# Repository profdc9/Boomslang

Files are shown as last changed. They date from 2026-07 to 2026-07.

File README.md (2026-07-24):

# Boomslang




A 3-channel ESP32-S3 pyrotechnic/model-rocket ignition controller. Hardware
(KiCad project, schematic, gerbers) is under `Boomslang/`; firmware is under
`firmware/` (PlatformIO, Arduino framework).

## ⚠️ Disclaimer — use at your own risk

This project fires pyrotechnic devices and/or model rocket motors. Incorrect
wiring, misconfiguration, a firmware bug, a hardware fault, or plain
operator error can cause unintended ignition, fire, injury, or property
damage. **This is a hobbyist project, provided AS-IS, with NO WARRANTY OF
ANY KIND** — express or implied, including no warranty of merchantability,
fitness for a particular purpose, or that it is safe, correct, reliable, or
free of defects.

By building, modifying, or using this hardware or firmware, you accept full
responsibility for:

- Verifying correct operation yourself, on your own hardware, before relying
  on any of it — including every safety feature described in this README.
- Complying with all applicable laws, regulations, and permitting
  requirements for pyrotechnics, explosives, and/or model rocketry in your
  jurisdiction.
- Following standard range-safety practice: safe distances, no bystanders
  in range, appropriate PPE, a real mechanical arm switch you trust, and
  never treating any software feature here as a substitute for that.

The author(s) and contributors accept **no liability** for any injury,
death, damage, or loss arising from building, modifying, or using this
project, to the fullest extent permitted by law.

## License

Dual-licensed by design, since this repo mixes source code and hardware
design files:

- **Firmware** (`firmware/`) is licensed under the [MIT License](LICENSE).
- **Hardware design files** (`Boomslang/` — KiCad schematic, PCB, gerbers)
  are licensed under [CC BY-SA 4.0](LICENSE-HARDWARE.txt).

Both are permissive and allow commercial use, but neither one waives the
disclaimer above — "you can use/modify/redistribute this" is a separate
question from "this is safe or fit for any particular purpose."

## WiFi access

The board hosts its own WiFi AP (no router needed) — SSID and password are
persisted settings (`wifiSsid`/`wifiPassword`, settings page), defaulting to
`boomslang` / `liftoff!`. **The password is this device's only access
control** — there's no separate login on top of it, so anyone who has it can
arm and fire. Change it from the default before using this anywhere it
matters. A password can also be left blank for an open, unencrypted network,
but that isn't recommended for the same reason.

Changes take effect only after the device is power-cycled or reset (the AP
isn't re-initialized at runtime) — you'll need to reconnect using the new
name/password afterward. SSID must be 1-32 characters; password must be
empty or 8-63 characters (the minimum WPA2-PSK allows).

The control pages are served over plain HTTP, not HTTPS — WPA2 already
encrypts the WiFi link itself, and adding TLS on top would mean a
self-signed certificate that a phone would flag as untrusted on every visit,
plus added latency on the page's frequent status polling, for a narrower
additional threat (another authenticated client on the same AP sniffing
traffic) than what WPA2 already covers.

**Relay (station) mode** (`wifiStationMode`, default **off**): instead of
hosting its own AP, the device can join `wifiSsid`/`wifiPassword` as a
client of an existing router, to relay through it when the operator needs
more distance from the pyrotechnics than the device's own AP range allows.
If it can't connect within 15 seconds (wrong password, out of range, router
down), it falls back to hosting its own AP instead — so a bad relay network
never leaves you locked out of the device with no way to disarm or abort.

This setting is deliberately **not a checkbox** on the settings page:
enabling it means anyone who can reach that external network can also reach
this device, so it requires typing the literal word `relay` into a text
box rather than a single accidental tap — blank or anything else both mean
"stay off, host my own AP" (the safe default), including if the field is
missing from the request entirely.

**Before you enable this, secure that router/network yourself — it's now
part of your access control, not just Boomslang's own password.** In its
own AP mode, WPA2 on the device is the entire perimeter. In relay mode,
that perimeter is whatever the router enforces: WPA2/WPA3 with a strong
password of its own, no other untrusted devices or guests on it, and
ideally a network used for nothing but this. A relay network that's open,
weakly secured, or shared with devices you don't control gives *anyone on
it* the same access as someone standing next to the device with its own
password — arming and firing included.

Either way — hosting an AP or joined as a station — the device also starts
an mDNS responder, so `http://boomslang.local` works regardless of which
mode ended up active or what IP a router's DHCP server happened to assign.

## Web UI pages

Four pages, all polling `/status.json` and posting to the same handful of
endpoints — the split below is purely how the browser organizes things, not
a backend/data-model split. Each has a small nav row (Main · Timing · Stats
· Settings) so it's obvious how to get back to the others.

- **`/` (Main)** — the operational screen, meant for actual field use:
  arm/fault/lockout status, battery voltage, each channel's checkbox + live
  continuity/firing state, and TRIGGER/ABORT/PANIC. Deliberately lean —
  timing setup and post-fire review live elsewhere so this screen stays fast
  to read and tap through during an actual arm/fire sequence.
- **`/timing`** — setup screen: the same channel checkboxes as Main (same
  `/select` endpoint — selection can be changed from either page) plus each
  channel's offset/duration in milliseconds and optional PWM cycling
  (Hz/duty%, see Trigger sequence below). No live operational state and no
  TRIGGER/ABORT/PANIC here.
- **`/stats`** — read-only review: peak and average current per channel
  from its most recent pulse (see Trigger sequence below).
- **`/config` (Settings)** — every persisted setting described throughout
  this README.

## Overcurrent fault protection

Each channel's IRLZ44N MOSFET has its own analog overcurrent comparator
(transistors Q5/Q10/Q16, sensing the 0.05Ω source shunt) that pulls that
channel's own gate to GND in hardware, in nanoseconds, with **no firmware
involved at all**. That's the actual protection for the transistor. All
three channels' comparators also pull a single shared, open-collector,
active-LOW `FAULT` line (GPIO1) — since it's wired-OR across all three,
firmware can tell *that* a channel faulted, but not *which* one.

The 0.05Ω figure above is just the schematic default (R1/R17/R31) — the
per-channel shunt resistance (`senseOhms`, settings page) is a runtime
setting used for the firing-current math (`readCurrentA()`), independently
of the comparator's own fixed hardware trip point. Valid range is
**0.01Ω–100Ω**, to accommodate a field-replaced shunt of a different value.

**The fault ISR** (`onFaultISR` in `firmware/src/main.cpp`) is a level-1
`attachInterrupt` on `FAULT`, `IRAM_ATTR`, and deliberately minimal: it does
exactly two things, a single register write forcing all three TRIGGER
outputs HIGH at once (not just the channel that faulted — the shared line
can't tell which one anyway, so every channel is shut down for consistency)
and setting a sticky `faultLatched` flag. Nothing else runs in the ISR
itself — no `Serial`, no heap, and critically no `analogRead()`, since the
ESP-IDF ADC driver takes a FreeRTOS mutex internally that `loop()` is
already holding on a regular basis; taking it again from ISR context would
be undefined behavior.

**Sampling SENSE for diagnostics** (which channel was drawing how much
current right as the fault hit) therefore happens in a separate,
dedicated FreeRTOS task (`faultSampleTask`), woken by the ISR via
`vTaskNotifyGiveFromISR`/`portYIELD_FROM_ISR` so it runs essentially the
instant the ISR returns, ahead of `loop()` or anything else. It's pinned to
the core opposite the Arduino loop/web server, at a priority high enough to
preempt normal code but below WiFi's own internal tasks. This snapshot is
best-effort — the hardware protection may have already cut current before
it runs — and is exposed as `fault_snapshot_a` in `/status.json` and shown
in the FAULT banner on the control page. If the banner reads "FAULT —
overcurrent detected" with no `(X.XXA Y.YYA Z.ZZA)` after it, that means
`fault_snapshot_a` was never populated for this event — either
`writeTriggerPinBlanked()`'s own fallback latched the fault directly
(covered below; it takes its own snapshot too, since it's normal task
context rather than ISR context and can safely call `analogRead()`
itself, unlike `onFaultISR()`), or a fault was latched some other way that
doesn't notify `faultSampleTask` (the boot-time check, for example).

**Clearing a fault**: `faultLatched` is a software latch, not
self-clearing. It clears automatically — no button, no endpoint — the
instant the device is `DISARMED` and the hardware `FAULT` line re-checks
clear (several reads over ~2ms, so a line chattering right at the trip
point doesn't get cleared into a still-live fault; see `loop()`'s
DISARMED-only fault-clearing pass in `main.cpp`). It's tied specifically
to being disarmed — never while armed, so a fault mid-sequence can't clear
itself out from under an operator who hasn't actually disarmed — which
matches the fact that a disarm+rearm is already required before
retriggering anyway (see `faultLockedOut()` below); there was no reason to
also require a separate manual "clear fault" button on top of that. A
reboot doesn't clear a persistent fault either: `FAULT` is checked at
boot, before the ISR is even attached, and latches immediately if still
asserted.

**Fault lockout** (`faultLockedOut()`/`notifyFaultOccurred()`,
`arm_state.cpp`): independent of `faultLatched` above — that flag only
tracks whether a fault is *currently* asserted/unacknowledged, and clears
automatically as soon as it's genuinely resolved and the device is
disarmed. This is a separate, sticky flag: once any fault has occurred, it
stays set — same shape as the PANIC lockout — unconditionally requiring a
fresh disarm+rearm before another TRIGGER is accepted, regardless of
`requireRearmAfterFire`, even after the fault itself has already cleared.
Cleared at the same disarm→rearm transition point every other lockout is.

**Live FAULT line indicator**: the main control page also shows a
`FAULT line: clear/ASSERTED` readout (`fault_pin_active` in
`/status.json`, a plain `digitalRead(PIN_FAULT)` taken fresh on every
poll), separate from the latched `fault` flag above. Since `faultLatched`
only clears automatically while disarmed, this raw reading is what tells
you whether the hardware comparators are asserting the line *right now* —
useful for telling "latched from a past event, line's gone high again"
apart from "still actively faulted."

**Leading-edge blanking on trigger-pin switching**: on real hardware,
pressing TRIGGER with no igniter/load connected was found to produce an
immediate `FAULT` with a 0A current snapshot — a switching transient at the
moment a trigger pin changes state, not a real overcurrent event (confirmed
by walking the actual shunt/comparator/snubber netlist: the RC snubber ties
drain-to-GND directly, not through the sense shunt, so there's no real
current path for a genuine fault with nothing connected). `firmware/src/
main.cpp`'s `writeTriggerPinBlanked()` now wraps the two deliberate
trigger-pin writes (fire-start in `startFirePulse()`, and the normal
pulse-end release in `loop()`) in a short critical section
(`FAULT_BLANKING_US`, `config.h`, default 10µs — tuned down from an
initial 30µs guess after bench testing confirmed the real switching
transient clears well within that window): interrupts are disabled
for that window, the pin is written, and `FAULT` is checked once directly
afterward — if it's already resolved, that reading is trusted and the
event is treated as filtered, not a fault.

Two subtleties this required getting right, since a plain
`delayMicroseconds()`-based wait would not have been safe here:

- `noInterrupts()`/`interrupts()` (not `detachInterrupt()`/
  `attachInterrupt()` + a bare delay) bounds the window deterministically —
  a plain busy-wait doesn't block task preemption, so a higher-priority
  task/ISR becoming ready mid-wait could otherwise extend the real gap well
  past `FAULT_BLANKING_US`. `delayMicroseconds()` itself is safe to call
  with interrupts disabled: it polls `micros()`, which reads a free-running
  hardware counter that keeps advancing regardless of the core's
  interrupt-enable state — unlike `delay()`/`vTaskDelay()`, which actually
  depend on the tick interrupt to wake back up, and would hang here.
- Disabling interrupts at the CPU level only defers *servicing* — it
  doesn't stop the GPIO peripheral's own edge-detector from latching a
  FALLING edge into its interrupt-status register during the window. Left
  alone, a transient that resolves *inside* the window would still fire
  `onFaultISR()` retroactively the instant interrupts are re-enabled, for
  an edge that's already history. `writeTriggerPinBlanked()` explicitly
  clears that latched status bit (`GPIO_STATUS_W1TC_REG`) before
  re-enabling, so a resolved transient is actually discarded.

None of this touches the real transistor protection described above — the
per-channel analog comparators keep working purely in hardware throughout,
completely independent of whether this interrupt is masked. What's
filtered is only the shared-line firmware echo (forced shutoff + the
sticky latch) reacting to a switching artifact instead of a real fault.

**Why `FAULT_BLANKING_US` isn't 0**: it's tempting to think a shorter
window is strictly better (less time other channels go unprotected by the
shared-line echo — the per-channel hardware protection is never affected
either way). Bench testing found a real lower bound, though: at `0`
(no wait at all), a genuine fault could be missed by `writeTriggerPinBlanked()`
entirely rather than filtered — the comparator's own output hadn't
necessarily finished settling into a stable level by the instant this
function checks it, so a real, ongoing fault could read as
"already resolved" and get discarded, only to be caught later by some
other, slower path with no diagnostic snapshot at all. `10µs` reliably
avoids that while still filtering the original no-load transient. The
delay also determines *where* on the fault current's natural rise/decay
curve the diagnostic snapshot below lands: shorter delay samples closer to
the true peak, longer delay samples further into the decay (current
doesn't collapse to zero the instant the comparator trips — the driver
stage and any loop inductance both take some real, if small, additional
time). `10µs` was chosen empirically on the bench, not derived
analytically — if the real transient/settling duration ever needs to be
known precisely, `DEBUG_FAULT_TIMING`/GPIO13 above is there for exactly
that.

**`writeTriggerPinBlanked()`'s fallback and multi-channel shutoff**: if
`FAULT` is still asserted once the blanking window elapses, this function
also samples SENSE for its own diagnostic snapshot (same reasoning as
`faultSampleTask` above — normal task context, so `analogRead()` is safe
here too) and forces every trigger pin off via the same atomic register
write `onFaultISR()` uses, mirroring what the ISR does for a fault that
isn't coincident with a trigger-pin write. This closes a real gap found
during testing: with a real load on one channel and a short on another,
if the short's fault was caught by this fallback (i.e. it happened right
at that *other* channel's own trigger-pin write) rather than by
`onFaultISR()`, the loaded channel could keep firing for longer than
intended — this function used to only set the sticky fault flags and rely
on `loop()`'s later `stopSequence()` call to shut off *other* channels,
reached only after that iteration's other work (continuity checks, etc.).
Forcing every pin off directly here, immediately, closes that gap the
same way the ISR always has.

The sampling happens *before* that forced shutoff, deliberately: forcing
every channel off first, before sampling, was found to reliably collapse
the diagnostic reading to 0A — unlike the local hardware protection, which
reacts in true analog time and was never the bottleneck here,
`analogRead()` itself is not deterministic (the underlying ESP-IDF driver
power-cycles the whole ADC peripheral and takes an internal mutex on every
single call), so forcing a shutoff immediately beforehand left nothing
meaningful to measure by the time sampling actually ran. Sampling first
trades a small amount of additional, ADC-read-bound latency before *other*
channels are forced off, for a snapshot that's actually usable — still
bounded well under the IRLZ44N's ~1ms SOA tolerance, just no longer
effectively instantaneous the way the plain register write is on its own.

Why a plain level-1 interrupt is enough: the IRLZ44N's SOA tolerates ~1ms at
full overcurrent, and even level-1 ISR latency on this chip is reliably
single-digit microseconds — comfortably inside that margin, especially
given the hardware analog protection has already started cutting current
before the ISR even runs. A `DEBUG_FAULT_TIMING` build flag (on by default
in `config.h`) toggles a spare pin (GPIO13) around ISR entry and the end of
SENSE sampling, so real end-to-end latency can be measured on a scope once
hardware exists.

**`DEBUG_DISABLE_FAULT_SHUTOFF`** (`config.h`, default **off**): a
bench-debug-only build flag used while diagnosing the switching transient
above. When on, it skips firmware's forced-HIGH/`stopSequence()` echo on a
fault, letting an in-progress pulse keep running through a `FAULT` trip
instead of being cut short — useful for observing what's actually
happening with no load connected. `faultLatched` is still set and still
blocks new triggers until disarmed and genuinely resolved, same as
always; only the forced shutoff of an already-running pulse is skipped.
It does **not** and cannot
affect the real per-channel hardware protection described above, which
runs in pure analog and has no firmware involvement at all. Must be off
for any real use with igniters/pyrotechnics connected.

## Audible / visible arming indicators

The board carries a buzzer output (`J6`, driven via `AUDIBLE`/GPIO41) and
onboard white/blue strobe LEDs (driven via `VISIBLE`/GPIO42). Both are owned
entirely by the firmware's arm state machine (`firmware/src/arm_state.cpp`)
— there's no manual on/off control for them, since a manual override would
just fight the automatic pattern.

**When they run:** only while the arm loop (the physical switch at `J5`) is
closed — i.e. during the `COUNTDOWN` and `READY` states. They're silent and
dark whenever the device is `DISARMED`; there's nothing to warn about when
the loop is open.

**Why two different patterns:** so the state can be told apart by ear or by
eye alone, without needing to look at the web UI:

| State | Tone | Pulse rate |
|---|---|---|
| `COUNTDOWN` | 440 Hz  | ~1 Hz (slow, 500ms on/off) |
| `READY` | 1000 Hz | ~2.5 Hz (fast, 200ms on/off) |

A low, slow pulse means the countdown is still running and firing is *not*
yet permitted (giving whoever closed the arm switch time to clear the area).
A higher, faster pulse means the countdown has elapsed and the device is
ready to fire.

**Tone stability:** `updateArmState()` runs every `loop()` iteration
(unthrottled, so potentially thousands of times per second), but only
touches the buzzer's LEDC output on an actual change — turning on, turning
off, the frequency changing, or the volume changing — rather than every
iteration. Arduino's `tone()`/`noTone()` aren't used here: `tone()`
reprograms the ESP32's LEDC PWM peripheral and resets phase on every call
(producing an audible click if called continuously — the original cause of
a choppy/glitchy buzzer sound), and it always drives a fixed 50% duty
cycle, which rules it out for volume control (below) regardless. Frequency
and duty are set independently instead, via `ledcChangeFrequency()`/
`ledcWrite()` (`AUDIBLE_LEDC_CHANNEL`, `config.h`).

**Volume:** `speakerVolume` (settings page, 0-10, default **10**) maps
linearly to 0-50% PWM duty cycle — 50% is as loud as a square-wave drive
gets (maximum RMS), so 10 reproduces the same loudness `tone()` always
used before this was configurable. Recomputed every `updateArmState()`
call, so changing it takes effect immediately, live, with no disarm/rearm
needed.

**Settings:** each channel can be silenced independently via the settings
page (`/config` on the web UI):

- `visibleWhenArmed` — strobe LEDs flash during `COUNTDOWN`/`READY` (default **on**)
- `audibleWhenArmed` — buzzer sounds during `COUNTDOWN`/`READY` (default **on**)
- `speakerVolume` — buzzer loudness, 0-10 (default **10**, see above)

All are persisted to flash (survive power cycles) and, like all settings
changes, can only be saved while the device is disarmed.

## Trigger sequence

Firing isn't one button per channel — the main control page lets you select
which channels to fire and, per channel, how long after pressing TRIGGER
that channel should fire, then fires the whole configured sequence off a
single press.

**Per channel:**
- A checkbox, on both the Main and Timing pages, to include that channel in
  the next trigger. **Not** persisted — it resets on every page load, so a
  stale "everything selected" state from a previous session can never carry
  over silently. It also resets on every device *reboot*, which the page
  detects on its own: `/status.json`'s `uptime_ms` resets to a small value
  on every boot, and if a poll ever sees it drop compared to the previous
  poll, that means the device restarted since then — the page then rebuilds
  its channel list from scratch on the next poll, so a browser tab left
  open across a power cycle can't keep showing checked boxes that no longer
  match the device's actual (cleared) selection.
- An **offset** in milliseconds (0-60000, default 0), on the Timing page,
  from the TRIGGER press to that channel's trigger output going low.
- A **duration** in milliseconds (0-30000, default 500), also on the Timing
  page, that the trigger output then stays low.

Offset and duration are both persisted settings
(`channelDelayMs`/`channelDurationMs`), saved to flash the moment you change
either one — same as every other setting, they survive a power cycle, so a
fixed show sequence doesn't need retyping every session. They're plain
milliseconds rather than seconds specifically for finer-grained control over
short pulses. Also same as every other setting: saving to flash requires
the device to be disarmed — a change made while armed still applies
immediately in RAM for that session, but won't survive a reboot until you
disarm and it actually gets persisted.

**PWM cycling** (`channelPwmHz`/`channelPwmDutyPercent`, Timing page, per
channel): instead of being continuously on for the whole duration, a
channel can instead cycle on/off within that same duration window — for a
lower average heating rate than a full-on pulse (e.g. slow-heating
nichrome/resistive element rather than an instant e-match). `channelPwmHz`
(0-300Hz, default **10Hz**, `0` disables PWM — continuously on for the
whole duration, exactly as before) sets the cycle rate; `channelPwmDutyPercent`
(0-100%, default **100%**) sets how much of each cycle is on. 100% duty
(the default) is treated the same as PWM being disabled — continuously on,
no cycling — so a fresh board fires exactly as it always did until duty is
deliberately lowered; 0% duty delivers no power at all for the whole
duration. This is a plain software timer in `loop()`, not hardware PWM.

**300Hz is a real, bench-measured ceiling, not just "doesn't need to be
precise."** The toggle logic can't act faster than `loop()` itself
iterates: at a PWM period comparable to one `loop()` iteration, both the
on-phase and off-phase end up bottlenecked by the same iteration time
instead of the requested durations, and duty accuracy collapses — 1000Hz
was measured converging toward ~50% regardless of configured duty,
regardless of how fast `loop()` was made to run. `loop()`'s own rate was
itself a real bottleneck worth fixing along the way: `WebServer::
handleClient()` calls a flat `delay(1)` whenever no HTTP client is
actively mid-request (i.e. most of the time), which is `vTaskDelay()`-
backed and rounds up to at least one full FreeRTOS tick (1ms, this
project's `CONFIG_FREERTOS_HZ=1000`) — capping `loop()` at ~1kHz
regardless of how much other per-iteration work was reduced. `main.cpp`'s
`setup()` now calls `server.enableDelay(false)` to remove that floor,
which alone raised the measured rate from ~1kHz to ~3kHz. At that rate,
300Hz (30 iterations/period) keeps duty tracking usable down to about 10%
duty; a `DEBUG_LOOP_RATE` build flag (`config.h`, on by default) logs the
actual measured rate over Serial once a second if this ever needs
re-checking on different hardware.

**Every PWM edge gets the same protection as a single trigger-on event**:
each on/off transition, not just the first, goes through
`writeTriggerPinBlanked()` (see Overcurrent fault protection above), so a
fault at any point during a PWM burst is caught exactly the same way it
would be for a plain single-shot fire. Turning *off* is always immediate;
before turning back *on* at each cycle, firmware re-checks fault/armed/
continuity — the same belt-and-suspenders re-check described below for the
initial fire-time check, just repeated at every cycle rather than once,
since a PWM burst can run for a while. A failed re-check stops that
channel's remaining cycles for the rest of the sequence rather than
retrying.

**Pressing TRIGGER** is only possible when `arm_state` is `READY`, there's no
active fault, no sequence is already running, and (if
`requireRearmAfterFire` is on) the device hasn't fired since it was last
armed. It schedules every selected channel's trigger output to go low at
`now + its configured offset`, for its configured duration, then
immediately blocks further TRIGGER presses until that sequence finishes
(you can never have two sequences in flight at once, regardless of
settings).

**At each channel's actual fire moment** — not just when TRIGGER was pressed
— the firmware re-checks armed state, fault, and continuity. An offset can
be long enough for something to change, so a channel that fails this
recheck is skipped (and logged) rather than aborting the rest of the
sequence. If the arm switch is opened mid-sequence, the gate drivers lose
power outright regardless of what firmware does — this recheck is
belt-and-suspenders, not the actual safety mechanism.

**`requireRearmAfterFire`** (settings page, default **on**): once a trigger
sequence has run, no further TRIGGER is accepted until the arm switch is
opened and closed again (a fresh disarm + countdown + `READY`). With it off,
another TRIGGER is accepted as soon as the current sequence finishes, no
rearm needed.

**Peak and average current**, per channel, for its most recent pulse: while
a channel's trigger output is low, `firmware/src/main.cpp`'s `loop()`
samples that channel's current sense on every iteration, tracking the
highest single sample (peak) and the running mean of all samples (average).
Both are reset at the start of each pulse and then simply held afterward —
so they remain readable (`peak_current_a`/`avg_current_a` in
`/status.json`, shown per channel on the `/stats` page) for the rest of the
session, until that channel fires again. Sampling continues every
iteration regardless of PWM on/off phase, so the average comes out
duty-cycle-weighted automatically — off-phase samples read ~0A and pull it
down proportionally — with no special-case math needed. The main control
page's live "FIRING" status shows this running average rather than the
instantaneous reading while a channel is actively firing, since the
instantaneous value is sampled at an arbitrary instant relative to the PWM
cycle (the page polls every 500ms) and would otherwise often show ~0A
simply by catching an off-phase, even with real current flowing during
on-phases.

## ABORT and PANIC buttons

Two more buttons sit below TRIGGER on the main control page, both backed by
a shared `stopSequence()` helper (`firmware/src/main.cpp`) that stops
things *immediately* — any channel mid-pulse has its trigger pin forced
back HIGH right away rather than waiting out the rest of the fire pulse,
and anything still scheduled (waiting on its configured delay) is
cancelled. Neither has a confirm dialog on the frontend, and neither is
gated on any precondition — an abort/panic button should always just work,
the instant it's tapped, like a real E-stop.

**ABORT** (`/abort`) just stops the sequence. It does **not** prevent
retriggering — if the device is still armed and ready afterward, TRIGGER is
available again immediately. Only enabled on the control page while a
sequence is actually running, since it has nothing to do otherwise.

**PANIC** (`/panic`) does the same immediate stop, and *additionally*
always sets a new lockout (`panicLockedOut()` in `arm_state`) requiring a
full disarm and rearm before another TRIGGER is accepted — unconditionally,
independent of `requireRearmAfterFire`, and regardless of whether anything
was actually firing when it was pressed. Always enabled on the control
page, since pressing it has an effect either way.

## Arm timeout (auto-lockout)

Guards against "armed and walked away": if the device sits in `READY` —
armed, past the countdown, but never actually triggered — for longer than a
configurable timeout, TRIGGER is refused until a fresh disarm and rearm,
even though the arm switch (`J5`) is still physically closed.

**`armTimeoutSec`** (settings page, default **600s / 10 minutes**, 0
disables it): the clock starts the instant `COUNTDOWN` transitions to
`READY`, not when the switch was first closed, so a long
`armCountdownSec` doesn't eat into the READY window. Once it elapses, the
control page shows "Arm timeout elapsed — disarm & rearm required before
triggering again" and TRIGGER is disabled, the same way it is for
`panicLockedOut()` — cleared at the same point every other lockout is: the
arm switch observed open, then closed again.

This is a **software-only** lockout, same family as PANIC and the
continuity/rearm lockouts above: it cannot re-power the gate drivers on its
own, and it cannot cut them either. It only blocks the firmware's own
`/trigger` handler. The hardware arm switch remains the actual power
interlock regardless of this setting — the buzzer/strobe pattern keeps
following `READY` normally throughout, since electrically the device really
is still armed.

## Continuity checks

`CONTINUITY1/2/3` sense the same way `SENSEFAILSAFE` does: ~1mA through a red
LED, whose forward voltage exceeds `LED_CLAMP_ARM_VOLTS` (1.25V,
`firmware/src/config.h`) when the loop (the igniter, in this case) is
actually closed. That threshold (`CONTINUITY_OK_RAW` in the same file) is
shared with the arm-loop sense, since it's the identical circuit at the
identical target voltage.

Beyond the per-channel status dot, continuity gates channel selection and
triggering in two independent ways:

**Arm-time continuity monitor** (`checkContinuityOnArm`, settings page,
default **on**): while armed (`COUNTDOWN` or `READY`), continuously verifies
that every *selected* channel still has continuity. If one doesn't, the
control page shows an error and TRIGGER is refused — but this is live, not
latched: it clears itself the instant continuity is restored, or the setting
is turned off, no disarm needed. While this setting is on, channel selection
is also locked while armed (the `/select` endpoint refuses changes), since
the set of channels being monitored can't shift out from under a live check
— disarm to change which channels are selected.

This monitor reads `channelContinuityCached` rather than sampling fresh
every `loop()` iteration — `main.cpp`'s `loop()` round-robins one
`analogRead()` per iteration across battery voltage and each channel's
continuity (`slowSampleStep`, cycling through `NUM_CHANNELS + 1` steps)
instead of sampling all four every time, so each value is at most a few
iterations stale (comfortably fast relative to what actually reacts to
them — this monitor is already explicitly best-effort/self-clearing, and
the low-voltage lockout below already debounces over 2 seconds). This was
one of several fixes to a real, measured bottleneck: each `analogRead()`
call was found to carry real, non-trivial overhead (the underlying
ESP-IDF driver power-cycles the whole ADC peripheral and takes an internal
lock on every call), and `loop()` was doing up to 9 of them per iteration
in the fully-armed-and-monitoring case. The pre-trigger check and the
per-channel fire-time recheck below both still call `hasContinuity()`
directly for a fresh, uncached read — this round-robin cache is only used
for the informational background monitor, never for a safety-relevant
check made right before actually energizing a channel.

**Pre-trigger continuity check** (`checkContinuityBeforeTrigger`, settings
page, default **on**): at the instant TRIGGER is pressed, re-verifies
continuity for every selected channel. If any fail, *nothing* fires, the
control page shows an error, and — unlike the live monitor above — this is a
hard lockout: a full disarm and rearm is required before another TRIGGER is
accepted, regardless of `requireRearmAfterFire` (that setting is about the
post-*successful*-fire case; this is a separate, always-strict rule for this
specific failure).

Both checks are additional to, not a replacement for, the per-channel
recheck already described under Trigger sequence above (which happens at
each channel's actual fire moment, not at the TRIGGER press, and only skips
that one channel rather than refusing the whole sequence).

## Battery voltage

The 12V supply is sensed on GPIO2 through a fixed 1:11 resistor divider
(`BATTERY_DIVIDER_RATIO` in `firmware/src/config.h` — a PCB-fixed ratio, not
a runtime setting like the current-sense shunts), after passing through a
series diode ahead of the divider. `readBatteryVoltage()` (`main.cpp`) adds
back that diode's forward drop (`BATTERY_DIODE_DROP_V`, 0.7V, also a
compile-time constant — it's a fixed part characteristic, not field-
adjustable) so `battery_v` reflects true battery voltage, not the
diode-reduced rail. The reading is shown on the main control page as
`battery_v`.

The low-voltage lockout decision (below) uses this exact same reading —
`updateArmState()` takes `battery_v` as a parameter rather than sampling
`PIN_BATTERY` a second time independently, which it originally did. The
two readings need to agree: they briefly didn't (a since-fixed bug), and
the lockout could compare an uncorrected value against the threshold while
the banner showed the corrected `battery_v`, so the displayed voltage in a
"Cannot arm — battery too low" message could be well above the threshold
it had supposedly tripped. Sharing one reading both fixes that class of
bug structurally (there's only one value to ever disagree with itself) and
avoids a redundant `analogRead()` every `loop()` iteration — see the
round-robin sampling note under Continuity checks below, which this same
mechanism also covers.

**Low-battery warning:** below `lowBatteryThresholdV` (settings page,
default **11.5V**), the battery readout on the control page turns orange and
bold and appends "LOW BATTERY". This is just a warning — on its own it
doesn't stop you from arming or triggering.

**Low-voltage lockout** (`lowVoltageLockoutEnabled`, default **on**): reuses
the same threshold to actually block operation, independent of the warning
display:

- If the arm switch closes while `battery_v` is under threshold, the device
  stays `DISARMED` instead of entering `COUNTDOWN`.
- If voltage drops below threshold *while already* in `COUNTDOWN` or
  `READY`, the device is forced back to `DISARMED` immediately — the same
  path as the arm switch opening, including aborting any in-flight trigger
  sequence.

Both cases are live, not latched: checked continuously, not just at the
moment the switch closes. If the switch is still closed when voltage drops
too low, the control page shows "Cannot arm — battery too low"; the instant
voltage recovers above threshold, arming proceeds normally on its own,
with no need to open and reclose the switch. Turn the lockout off in
settings to arm anyway regardless of voltage (e.g. bench testing on a
supply that's intentionally below threshold) while keeping the warning
display active.

**Debounce and hysteresis** on the voltage check itself (`arm_state.cpp`),
addressing two failure modes a single raw comparison would otherwise have:

- *Boundary flapping* — a reading oscillating right at the threshold (ADC
  noise, supply ripple) could otherwise flap the lockout in and out rather
  than settling. Once locked out, voltage must recover past
  `lowBatteryThresholdV + 0.3V` (not just past the threshold itself) before
  the lockout clears.
- *Self-induced false trip* — firing an igniter draws real current through
  the same 12V rail being sensed, so a fire pulse can sag `battery_v`
  momentarily. The low-voltage condition must hold steady for 2 seconds
  (comfortably longer than a typical `channelDurationMs` pulse, or a short
  multi-channel burst) before the lockout actually engages, so a firing
  event's own transient sag isn't mistaken for a real low battery.

This is the same debounce shape `SENSEFAILSAFE` already uses for the arm
switch itself, just with a longer window and added hysteresis suited to a
noisier, slower-moving analog signal rather than a mechanical switch.

## Factory reset

`PIN_FACTORY_RESET` (GPIO14) is pulled up internally and checked once,
early in `setup()`, before settings are loaded. Ground it — a jumper or
button to GND — before powering the board up, and every setting resets to
its compiled-in default and is immediately persisted to flash, overwriting
whatever was there. It's checked with a few reads over a couple of
milliseconds rather than a single instantaneous one, so a pin still
settling right after `pinMode()` doesn't trigger a reset by accident.

This only runs at boot, from a floating/undriven starting point — there's
no runtime "hold this pin for 10 seconds" monitor. GPIO14 has no strapping
or other special function on the ESP32-S3 (unlike GPIO12 on the *original*
ESP32, a common source of outdated advice online — that specific gotcha
doesn't carry over to the S3), and is otherwise unconnected on the PCB.

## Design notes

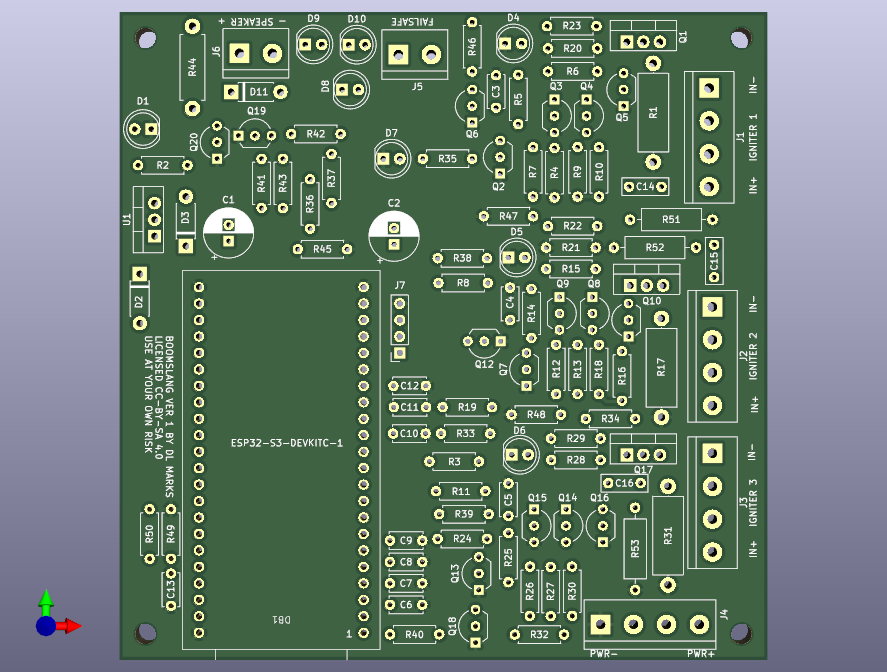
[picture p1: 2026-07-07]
Boomslang/Boomslang.png

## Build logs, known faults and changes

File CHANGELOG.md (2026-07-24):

# Changelog

All notable changes to this project are documented here. Format follows
[Keep a Changelog](https://keepachangelog.com/en/1.1.0/).

## [Unreleased]

## [0.1.7] - 2026-07-24

### Fixed

- `channelPwmHz` at high frequencies produced a much higher actual duty
  cycle than configured (e.g. 10% requested measured as ~50%): `loop()`
  can't toggle a pin faster than it can complete one full iteration, and
  the requested PWM period was comparable to or shorter than that. Traced
  the iteration time itself to `WebServer::handleClient()`'s flat
  `delay(1)` whenever no client is actively mid-request (`vTaskDelay()`-
  backed, rounds up to at least one full 1ms FreeRTOS tick), which
  single-handedly capped `loop()` at ~1kHz regardless of anything else in
  it. Calling `server.enableDelay(false)` in `setup()` removed that floor,
  raising the measured rate from ~1kHz to ~3kHz. `channelPwmHz`'s valid
  range lowered from 0-1000Hz to 0-300Hz to match what's actually
  achievable with usable duty accuracy at the new rate (down to ~10%
  duty); default duty changed to 100% and default frequency to 10Hz, and
  100%/0% duty are now special-cased to skip the toggle machinery
  entirely (100% behaves as continuously on, 0% delivers no power) rather
  than cycling pointlessly with a 0ms on- or off-phase.
- Deduplicated `PIN_BATTERY` being read twice per `loop()` iteration —
  once independently in `arm_state.cpp`'s low-voltage lockout decision,
  once in `main.cpp` for the displayed `battery_v`. `updateArmState()` now
  takes the reading as a parameter instead of sampling it a second time.
- Added round-robin sampling for battery voltage and each channel's
  continuity (`main.cpp`'s `loop()`, `slowSampleStep`): at most one of
  these four `analogRead()` calls happens per iteration, cycling through
  the rest, instead of all four every time. None of them need
  per-iteration freshness (the low-voltage lockout already debounces over
  2s; the arm-time continuity monitor is already self-clearing/best-
  effort) — this was found while investigating the PWM timing issue
  above, since `analogRead()` itself carries real overhead (the ESP-IDF
  driver power-cycles the whole ADC peripheral and takes an internal lock
  on every call), and `loop()` was doing up to 9 of these calls per
  iteration in the fully-armed-and-monitoring case. Safety-relevant
  continuity re-checks (PWM re-toggle, scheduled-fire pass) are
  unaffected — they still call `hasContinuity()` directly for a fresh
  read, never this cache.
- Added a `DEBUG_LOOP_RATE` build flag (`config.h`, on by default) that
  logs `loop()`'s actual iterations/sec over Serial once a second — added
  to measure the real numbers behind the fixes above; harmless to leave
  on.

## [0.1.6] - 2026-07-23

### Changed

- Nav row on all four pages (Main/Timing/Stats/Settings) is now a 2x2
  grid of button-styled blocks instead of an inline text row, with the
  font size doubled for easier one-handed tapping. Main page's Battery
  and FAULT line readouts moved onto a single row to make room.

### Added

- Per-channel PWM cycling during a fire pulse (`channelPwmHz`/
  `channelPwmDutyPercent`, Timing page, new `/channel_pwm_hz` and
  `/channel_pwm_duty` endpoints): instead of being continuously on for the
  whole duration, a channel can instead cycle on/off within it, for a
  lower average heating rate than a full-on pulse. `channelPwmHz` (0-1000,
  default 10Hz, 0 disables) sets the rate; `channelPwmDutyPercent` (0-100,
  default 100%) sets how much of each cycle is on — 100% behaves exactly
  like PWM being disabled (continuously on), so a fresh board fires
  exactly as before until duty is deliberately lowered, and 0% delivers no
  power at all. Every PWM edge, not just the first, goes through the same
  `writeTriggerPinBlanked()` fault-blanking protection as a single-shot
  fire; turning back on at each cycle re-checks fault/armed/continuity,
  same reasoning as the existing fire-time recheck, and stops the
  channel's remaining cycles rather than retrying if any fail.

### Fixed

- Main control page's live "FIRING" current readout showed 0A for a
  PWM-cycled channel most of the time: it displayed the instantaneous
  `last_current_a` reading, sampled at whatever arbitrary instant
  `/status.json` happened to be polled (every 500ms) — which for a
  lower-duty-cycle channel often lands on an off-phase. Now shows the
  running average (`avg_current_a`) while firing instead, which already
  comes out duty-cycle-weighted for free (off-phase samples read ~0A and
  pull it down proportionally, no special-case math needed) and updates
  continuously regardless of which PWM phase the poll happens to catch.

## [0.1.5] - 2026-07-22

### Fixed

- Hardware: overcurrent comparator's pull-down transistor base resistor
  reduced from 1k to 100R. Scoped bench testing found the slower base
  resistor let fault current overshoot well past the ~13A trip threshold
  (38A) before the gate was actually pulled down; 100R speeds up that
  transistor's reaction, cutting the overshoot to ~15A. Verified in both
  a QUCS-S/ngspice simulation (`Simulations/ThresholdTrip`, now in the
  repo) and on the bench.

## [0.1.4] - 2026-07-22

### Fixed

- False `FAULT` trip on every TRIGGER press with no load connected: a
  switching transient at the moment a trigger pin changes state was
  tripping the shared hardware `FAULT` line even with zero real current
  (confirmed by walking the shunt/comparator/snubber netlist — the RC
  snubber ties drain-to-GND directly, not through the sense shunt, so
  there was no real fault path with nothing connected). Added software
  leading-edge blanking (`writeTriggerPinBlanked()`, `FAULT_BLANKING_US`
  in `config.h`, default 10µs — tuned down from an initial 30µs guess
  after bench testing): a deterministic, interrupt-disabled
  critical section around each deliberate trigger-pin write that filters
  the transient without touching the actual per-channel hardware
  protection (which runs in pure analog and was never affected either
  way). Explicitly clears the GPIO's latched interrupt-status bit before
  re-enabling interrupts, since a masked-but-resolved edge would
  otherwise still fire retroactively.
- `writeTriggerPinBlanked()`'s fallback path (a fault still asserted after
  the blanking window) now also captures its own `fault_snapshot_a`
  diagnostic reading, instead of leaving `fault_snapshot_valid` false.
  Unlike `onFaultISR()`, this path runs in normal task context, so it can
  safely call `analogRead()` directly rather than relying on
  `faultSampleTask`'s ISR-notification handoff, which nothing here was
  waking.
- Low-voltage arm lockout could trip (or fail to) at a voltage that
  disagreed with the displayed reading: `arm_state.cpp`'s
  `sampleBatteryVoltage()` — used for the actual lockout decision — never
  got the `BATTERY_DIODE_DROP_V` correction added to `main.cpp`'s
  `readBatteryVoltage()` (used for the displayed `battery_v`), so a
  "Cannot arm — battery too low" message could show a voltage well above
  the threshold it had supposedly tripped. Both readings now apply the
  same correction.
- Main/Timing pages could show stale checked channel checkboxes after a
  device reboot: channel selection was never persisted (by design), but
  a browser tab left open across a restart kept showing its pre-restart
  checked state, since checkboxes were only synced from the server once,
  on first page load. `/status.json` now includes `uptime_ms`; both pages
  detect it dropping (proof of a restart) and rebuild the channel list
  from server truth on the next poll.
- A `FAULT` didn't require a disarm+rearm before retriggering: only the
  immediate `faultLatched` flag blocked triggering, and that cleared as
  soon as the fault itself resolved — with nothing else requiring the
  arm switch to actually be cycled first, unlike every other lockout
  (PANIC, pre-trigger continuity failure, arm timeout). Added a new
  sticky `faultLockedOut()`/`notifyFaultOccurred()` pair (`arm_state.cpp`,
  same shape as the PANIC lockout), set the instant any fault latches and
  cleared only at the same disarm→rearm transition every other lockout
  uses.
- Removed the "Clear Fault Latch" button and `/clear_fault` endpoint.
  `loop()` now auto-clears a latched fault the instant the device is
  `DISARMED` and the hardware line re-verifies clear (same multi-sample
  ~2ms re-check the old endpoint did) — never while armed. Since a fresh
  disarm+rearm is already required before retriggering (see the lockout
  above), tying the clear to the disarm half of that cycle removes a
  redundant manual step, and incidentally removes an ordering ambiguity
  the manual button had (rearming before vs. after actually clicking
  clear).
- Fixed a real gap in `writeTriggerPinBlanked()`'s fallback (the path that
  catches a fault occurring exactly at a trigger-pin write, e.g. a short
  present before a channel ever turns on): it only set the sticky fault
  flags and relied on `loop()`'s later `stopSequence()` call to shut off
  *other* channels, reached only after that iteration's other work
  (continuity checks, etc.). With a real load on one channel and a short
  on another, the loaded channel could keep firing longer than intended.
  Now forces every trigger pin off immediately via the same atomic
  register write `onFaultISR()` uses, closing the gap the same way the
  ISR always has.
- `FAULT_BLANKING_US` bench-validated at 10µs (down from 30µs, briefly
  tried at 0µs): at 0, the comparator's own output hadn't necessarily
  finished settling by the time `writeTriggerPinBlanked()` checked it, so
  a genuine fault could be missed by that function entirely (caught later
  by a different path with no diagnostic snapshot) rather than filtered.
  Also reordered that function's fallback to sample SENSE *before* forcing
  the shutoff above, rather than after: `analogRead()` is not
  deterministic (the ADC driver power-cycles the whole peripheral and
  takes an internal mutex on every call), and forcing shutoff first was
  found to reliably collapse the diagnostic reading to 0A. Sampling first
  trades a small amount of additional latency before other channels are
  forced off (bounded well under the ~1ms SOA tolerance) for a snapshot
  that's actually meaningful.

### Added

- `DEBUG_DISABLE_FAULT_SHUTOFF` bench-debug build flag (`config.h`,
  default off): used while diagnosing the above, lets an in-progress
  pulse keep running through a `FAULT` trip instead of being cut short,
  for observing behavior with no load connected. Does not and cannot
  affect the real hardware protection.
- Buzzer volume control (`speakerVolume`, settings page, 0-10, default
  10): maps linearly to 0-50% PWM duty cycle. Required moving the buzzer
  off `tone()`/`noTone()` entirely — `tone()` always forces a fixed 50%
  duty cycle internally, incompatible with variable volume — onto direct
  `ledcChangeFrequency()`/`ledcWrite()` calls that set frequency and duty
  independently, each only re-issued on an actual change (same reasoning
  as the earlier choppy-buzzer fix). Takes effect live while armed, no
  rearm needed.

### Changed

- Current-sense shunt resistance (`senseOhms`, settings page) valid range
  widened from 0.001-10Ω to 0.01-100Ω, to accommodate a wider range of
  field-replaced shunt values.

## [0.1.3] - 2026-07-21

### Added

- Live FAULT line indicator on the main control page (`fault_pin_active`
  in `/status.json`), a raw `digitalRead(PIN_FAULT)` taken on every poll —
  distinct from the existing latched `fault` flag, which only clears via
  Clear Fault Latch.

### Fixed

- Battery voltage reading now accounts for the series diode ahead of the
  sense divider, adding back its ~0.7V forward drop
  (`BATTERY_DIODE_DROP_V`) so `battery_v` reflects true battery voltage
  rather than reading low.
- Choppy/glitchy arming buzzer: `tone()` was being re-issued on every
  `loop()` iteration (unthrottled, up to thousands of times/sec) instead
  of only when the tone actually starts, stops, or changes frequency.
  `tone()` reprograms the LEDC PWM peripheral each call, which resets
  phase and clicks audibly — now edge-triggered.

### Changed

- Continuity/arm-loop LED-clamp sense threshold (`LED_CLAMP_ARM_VOLTS`)
  lowered from 1.5V to 1.25V to better match the red LED's actual forward
  voltage.

## [0.1.2] - 2026-07-14

### Added

- Arm timeout auto-lockout: if `READY` is held longer than a configurable
  `armTimeoutSec` (default 600s, 0 disables) without triggering, TRIGGER is
  refused until a fresh disarm and rearm, even though the arm switch is
  still physically closed. Software-only, same lockout family as PANIC;
  does not touch the physical arm loop or the buzzer/strobe pattern.

## [0.1.1] - 2026-07-06

### Added

- Hardware: RC snubbers on each channel's IRLZ44N MOSFET drain, to damp
  switching transients from the igniter/wiring inductance.

## [0.1.0] - 2026-07-06

Initial release.

### Added

- Hardware: initial KiCad design (schematic, PCB, gerbers) for a 3-channel
  ESP32-S3 pyrotechnic/model-rocket ignition controller.
- Firmware: WiFi AP + mobile-first web control page, per-channel firing,
  current sensing, and continuity/fault sensing.
- Hardware overcurrent fault ISR that forces all three trigger outputs high
  immediately on a shared FAULT signal, with a notified FreeRTOS task
  sampling peak firing current for post-fault diagnostics without touching
  the time-critical shutoff path.
- Persistent, flash-backed (NVS) settings with a dedicated web settings
  page — every configurable value in this changelog is one of these.
- Arm/failsafe state machine (`DISARMED` → `COUNTDOWN` → `READY`) with a
  configurable countdown, distinct audible/visible indication per state,
  and a trigger-sequence firing model (per-channel selection + delay).
- Continuity-based channel selection gating: a live, self-clearing monitor
  while armed, and a stricter pre-trigger check with its own disarm/rearm
  lockout, independent of each other and of the post-fire rearm lockout.
- Battery voltage sensing (GPIO2, resistor divider), a configurable
  low-battery warning, and a low-voltage lockout — with debounce and
  hysteresis — that blocks arming or forces a disarm if voltage drops while
  already armed.
- Continuous audible tone while a trigger sequence is running (distinct
  from the normal pulsed arming tone), plus ABORT (stops firing, no
  lockout) and PANIC (stops firing, unconditional disarm/rearm lockout)
  buttons.
- Per-channel offset and duration in milliseconds (replacing a single
  fixed global pulse width), plus peak/average current registers recorded
  per channel for each pulse.
- Split the web UI into four pages: Main (operational), Timing (offset/
  duration setup), Stats (peak/average current review), and Settings.
- Configurable WiFi SSID/password (default `boomslang` / `liftoff!`),
  replacing hardcoded credentials.
- Hardware revision: GPIO2 battery-voltage sense breakout, GPIO12-14
  broken out as spare test points.
- Dual licensing (MIT for firmware, CC BY-SA 4.0 for hardware design
  files) and a use-at-your-own-risk disclaimer.
- `CONTRIBUTING.md` and README license badges.
- Factory-reset pin (GPIO14, internally pulled up, checked once at boot):
  grounding it before power-up resets every setting to its compiled-in
  default.
- WiFi relay (station) mode (default off): joins an existing router as a
  client instead of hosting its own AP, for more distance between operator
  and pyrotechnics, falling back to hosting its own AP if that connection
  fails so the device is never left unreachable. Enabling it requires
  typing the literal word "relay" into a settings-page text field rather
  than a checkbox, since it means anyone who can reach that external
  network can also reach this device. mDNS (`boomslang.local`) now starts
  in either mode.

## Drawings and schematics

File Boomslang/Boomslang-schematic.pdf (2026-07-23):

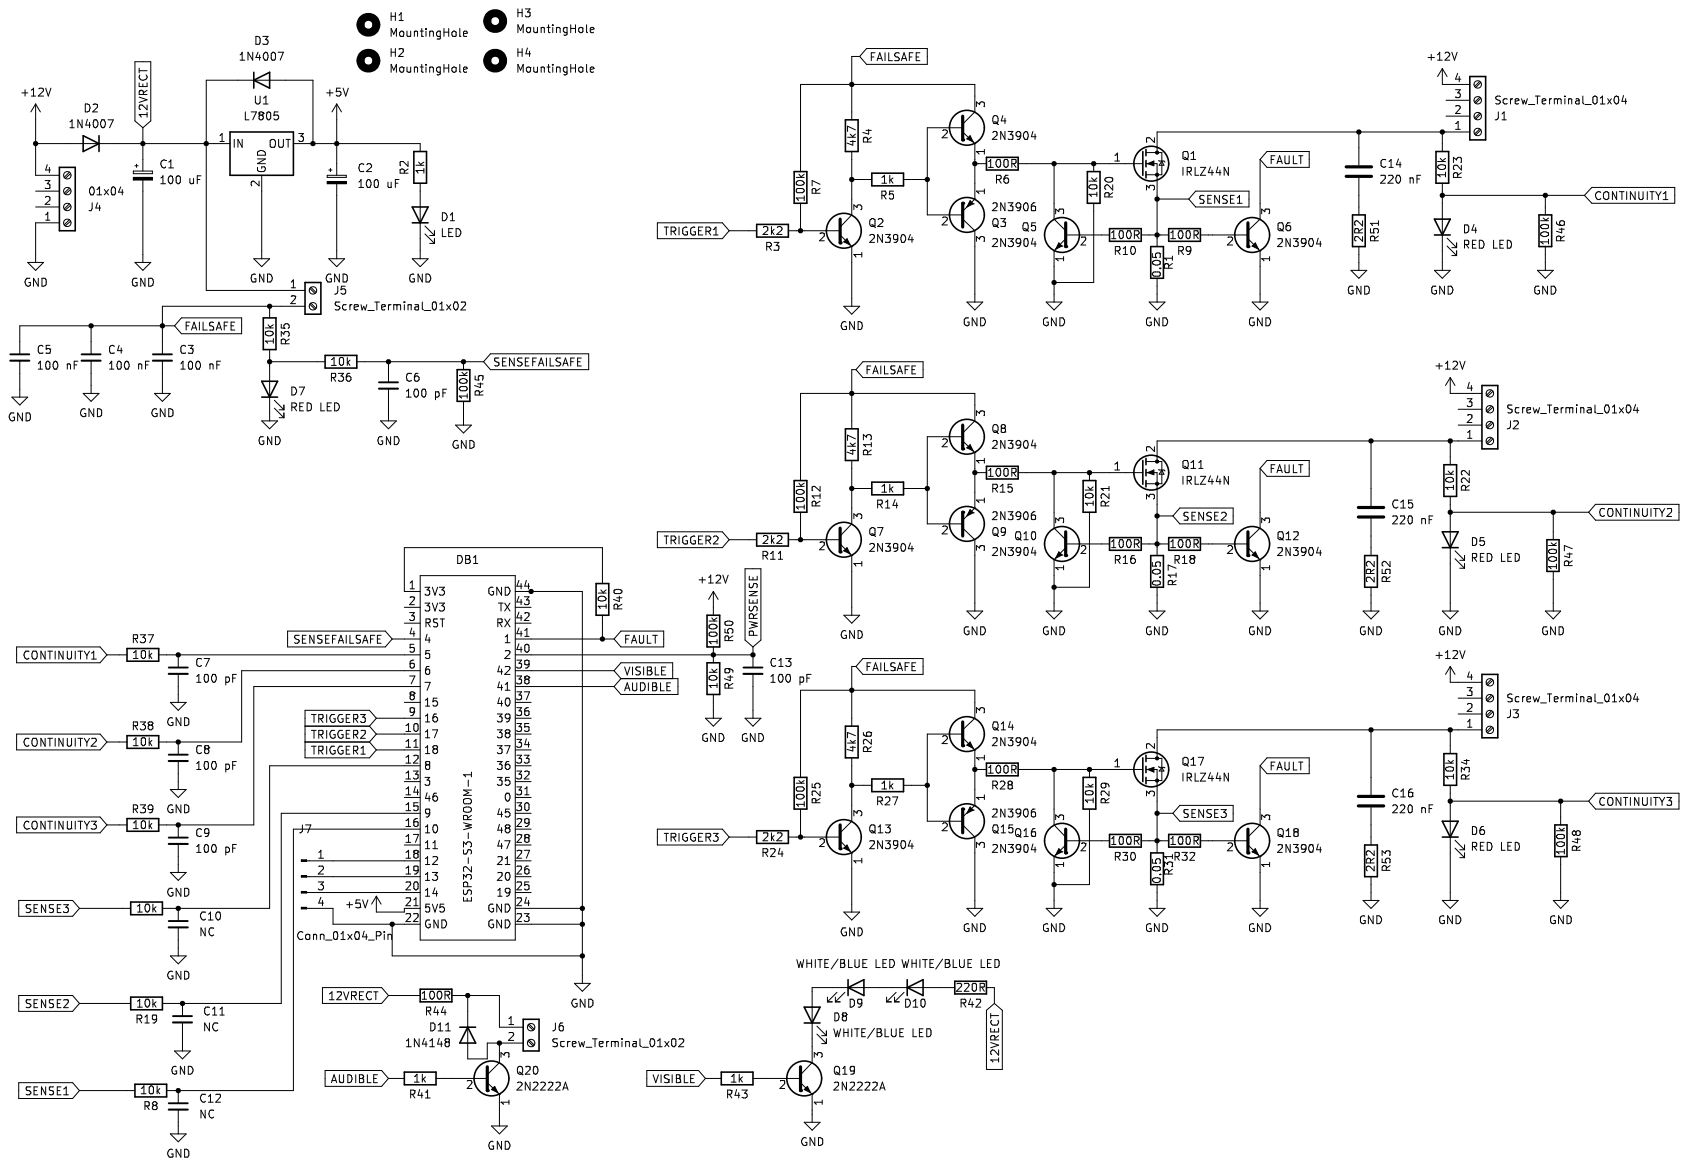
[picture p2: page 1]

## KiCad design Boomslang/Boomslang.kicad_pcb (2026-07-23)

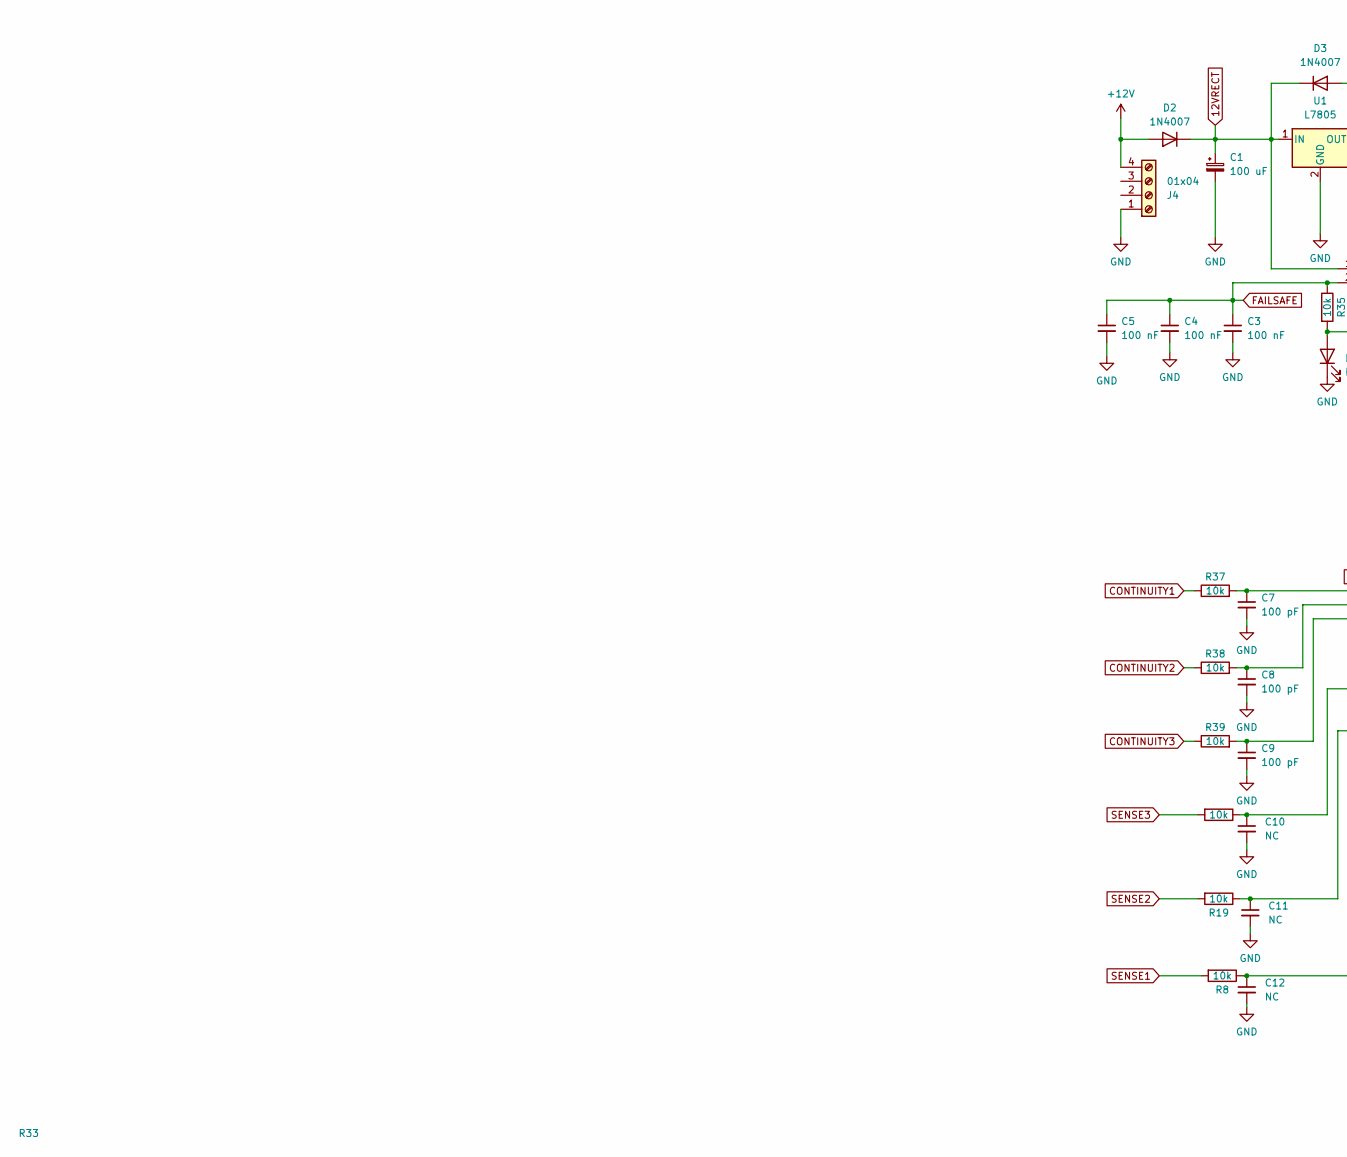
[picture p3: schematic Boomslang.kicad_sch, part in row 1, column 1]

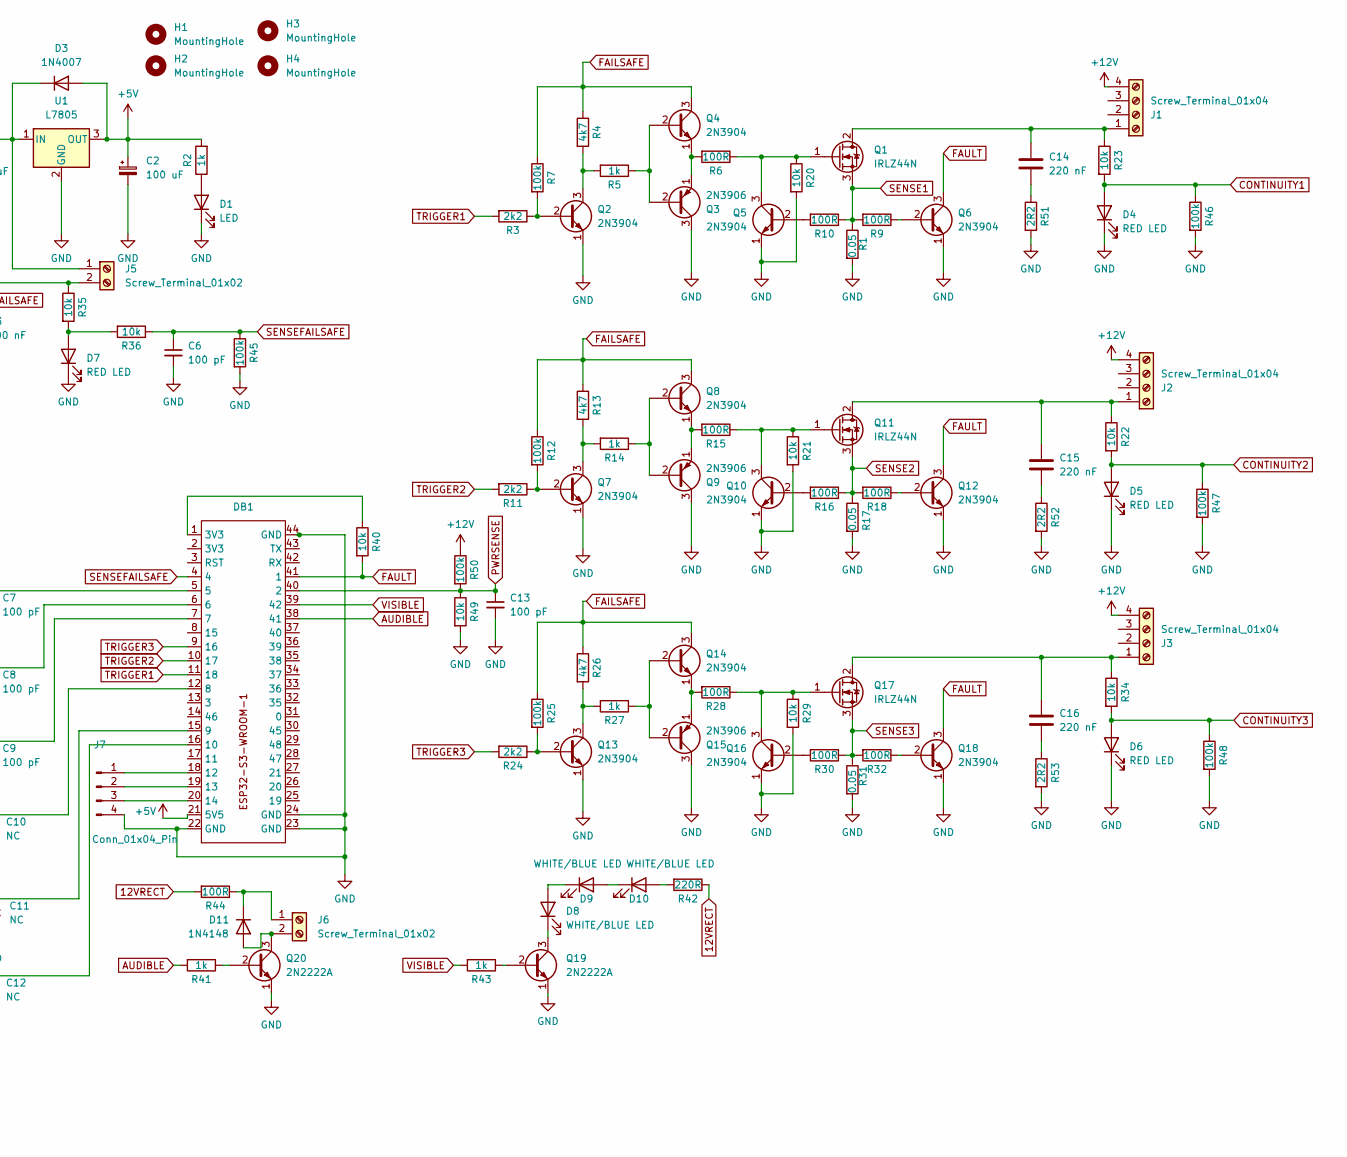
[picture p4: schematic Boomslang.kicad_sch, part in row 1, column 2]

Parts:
C1, C2: 100 uF; CP_Radial_D7.5mm_P2.50mm
C3, C4, C5: 100 nF; C_Disc_D5.0mm_W2.5mm_P5.00mm
C6, C7, C8, C9, C13: 100 pF; C_Disc_D5.0mm_W2.5mm_P5.00mm
C10, C11, C12: NC; C_Disc_D5.0mm_W2.5mm_P5.00mm
C14, C15, C16: 220 nF; C_Rect_L7.0mm_W2.5mm_P5.00mm
D1: LED; LED_D5.0mm
D2, D3: 1N4007; D_DO-41_SOD81_P7.62mm_Horizontal
D4, D5, D6, D7: RED LED; LED_D5.0mm
D8, D9, D10: WHITE/BLUE LED; LED_D5.0mm
D11: 1N4148; D_DO-41_SOD81_P7.62mm_Horizontal
DB1: ESP32-S3
H1, H2, H3, H4: MountingHole; MountingHole_3.2mm_M3
J1, J2, J3: Screw_Terminal_01x04; TerminalBlock_bornier-4_P5.08mm
J4: 01x04; TerminalBlock_bornier-4_P5.08mm
J5, J6: Screw_Terminal_01x02; TerminalBlock_bornier-2_P5.08mm
J7: Conn_01x04_Pin; PinSocket_1x04_P2.54mm_Vertical
Q1, Q11, Q17: IRLZ44N; TO-220-3_Vertical
Q2, Q4, Q5, Q6, Q7, Q8, Q10, Q12, Q13, Q14, Q16, Q18: 2N3904; TO-92_Inline_Wide
Q3, Q9, Q15: 2N3906; TO-92_Inline_Wide
Q19, Q20: 2N2222A; TO-92_Inline_Wide
R1, R17, R31: 0.05; R_Axial_DIN0414_L11.9mm_D4.5mm_P15.24mm_Horizontal
R2, R5, R14, R27, R41, R43: 1k; R_Axial_DIN0207_L6.3mm_D2.5mm_P7.62mm_Horizontal
R3, R11, R24: 2k2; R_Axial_DIN0207_L6.3mm_D2.5mm_P7.62mm_Horizontal
R4, R13, R26: 4k7; R_Axial_DIN0207_L6.3mm_D2.5mm_P7.62mm_Horizontal
R6, R9, R10, R15, R16, R18, R28, R30, R32: 100R; R_Axial_DIN0207_L6.3mm_D2.5mm_P7.62mm_Horizontal
R7, R12, R25, R45, R46, R47, R48, R50: 100k; R_Axial_DIN0207_L6.3mm_D2.5mm_P7.62mm_Horizontal
R8, R19, R20, R21, R22, R23, R29, R33, R34, R35, R36, R37, R38, R39, R40, R49: 10k; R_Axial_DIN0207_L6.3mm_D2.5mm_P7.62mm_Horizontal
R42: 220R; R_Axial_DIN0207_L6.3mm_D2.5mm_P7.62mm_Horizontal
R44: 100R; R_Axial_DIN0411_L9.9mm_D3.6mm_P12.70mm_Horizontal
R51, R52, R53: 2R2; R_Axial_DIN0309_L9.0mm_D3.2mm_P12.70mm_Horizontal
U1: L7805; TO-220-3_Vertical

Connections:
12VRECT: C1.1, D2.1 (K), D3.1 (K), J5.1, R42.1, R44.2, U1.1 (IN)
+5V: C2.1, D3.2 (A), DB1.21 (5V5), R2.2, U1.3 (OUT)
+12V: D2.2 (A), J1.4, J2.4, J3.4, J4.4, R50.1
AUDIBLE: DB1.38 (41), R41.2
CONTINUITY1: D4.2 (A), R23.2, R37.1, R46.1
CONTINUITY2: D5.2 (A), R22.2, R38.1, R47.1
CONTINUITY3: D6.2 (A), R34.2, R39.1, R48.1
FAILSAFE: C3.1, C4.1, C5.1, J5.2, Q4.3 (C), Q8.3 (C), Q14.3 (C), R4.1, R7.1, R12.1, R13.1, R25.1, R26.1, R35.1
FAULT: DB1.41 (1), Q6.3 (C), Q12.3 (C), Q18.3 (C), R40.2
GND: C1.2, C2.2, C3.2, C4.2, C5.2, C6.2, C7.2, C8.2, C9.2, C10.2, C11.2, C12.2, C13.2, D1.1 (K), D4.1 (K), D5.1 (K), D6.1 (K), D7.1 (K), DB1.22 (GND), DB1.23 (GND), DB1.24 (GND), DB1.44 (GND), J4.1, J7.4, Q2.1 (E), Q3.3 (C), Q5.1 (E), Q6.1 (E), Q7.1 (E), Q9.3 (C), Q10.1 (E), Q12.1 (E), Q13.1 (E), Q15.3 (C), Q16.1 (E), Q18.1 (E), Q19.1 (E), Q20.1 (E), R1.2, R17.2, R20.2, R21.2, R29.2, R31.2, R45.2, R46.2, R47.2, R48.2, R49.2, R51.2, R52.2, R53.2, U1.2 (GND)
unnamed: C7.1, DB1.5, R37.2
unnamed: C8.1, DB1.6, R38.2
unnamed: C9.1, DB1.7, R39.2
unnamed: C14.2, R51.1
unnamed: C15.2, R52.1
unnamed: C16.2, R53.1
unnamed: D1.2 (A), R2.1
unnamed: D7.2 (A), R35.2, R36.2
unnamed: D8.2 (A), D9.1 (K)
unnamed: D8.1 (K), Q19.3 (C)
unnamed: D10.2 (A), R42.2
unnamed: D9.2 (A), D10.1 (K)
unnamed: D11.2 (A), J6.2, Q20.3 (C)
unnamed: D11.1 (K), J6.1, R44.1
unnamed: DB1.1 (3V3), R40.1
unnamed: C10.1, DB1.12 (8), R33.1
unnamed: C11.1, DB1.15 (9), R19.1
unnamed: C12.1, DB1.16 (10), R8.1
unnamed: DB1.18 (12), J7.1
unnamed: DB1.19 (13), J7.2
unnamed: DB1.20 (14), J7.3
unnamed: C14.1, J1.1, Q1.2 (D), R23.1
unnamed: C15.1, J2.1, Q11.2 (D), R22.1
unnamed: C16.1, J3.1, Q17.2 (D), R34.1
unnamed: Q1.1 (G), Q5.3 (C), R6.1, R20.1
unnamed: Q2.2 (B), R3.1, R7.2
unnamed: Q2.3 (C), R4.2, R5.2
unnamed: Q3.2 (B), Q4.2 (B), R5.1
unnamed: Q3.1 (E), Q4.1 (E), R6.2
unnamed: Q5.2 (B), R10.2
unnamed: Q6.2 (B), R9.1
unnamed: Q7.2 (B), R11.1, R12.2
unnamed: Q7.3 (C), R13.2, R14.2
unnamed: Q8.2 (B), Q9.2 (B), R14.1
unnamed: Q8.1 (E), Q9.1 (E), R15.2
unnamed: Q10.2 (B), R16.2
unnamed: Q10.3 (C), Q11.1 (G), R15.1, R21.1
unnamed: Q12.2 (B), R18.1
unnamed: Q13.2 (B), R24.1, R25.2
unnamed: Q13.3 (C), R26.2, R27.2
unnamed: Q14.2 (B), Q15.2 (B), R27.1
unnamed: Q14.1 (E), Q15.1 (E), R28.2
unnamed: Q16.2 (B), R30.2
unnamed: Q16.3 (C), Q17.1 (G), R28.1, R29.1
unnamed: Q18.2 (B), R32.1
unnamed: Q19.2 (B), R43.1
unnamed: Q20.2 (B), R41.1
PWRSENSE: C13.1, DB1.40 (2), R49.1, R50.2
SENSE1: Q1.3 (S), R1.1, R8.2, R9.2, R10.1
SENSE2: Q11.3 (S), R16.1, R17.1, R18.2, R19.2
SENSE3: Q17.3 (S), R30.1, R31.1, R32.2, R33.2
SENSEFAILSAFE: C6.1, DB1.4, R36.1, R45.1
TRIGGER1: DB1.11 (18), R3.2
TRIGGER2: DB1.10 (17), R11.2
TRIGGER3: DB1.9 (16), R24.2
VISIBLE: DB1.39 (42), R43.2

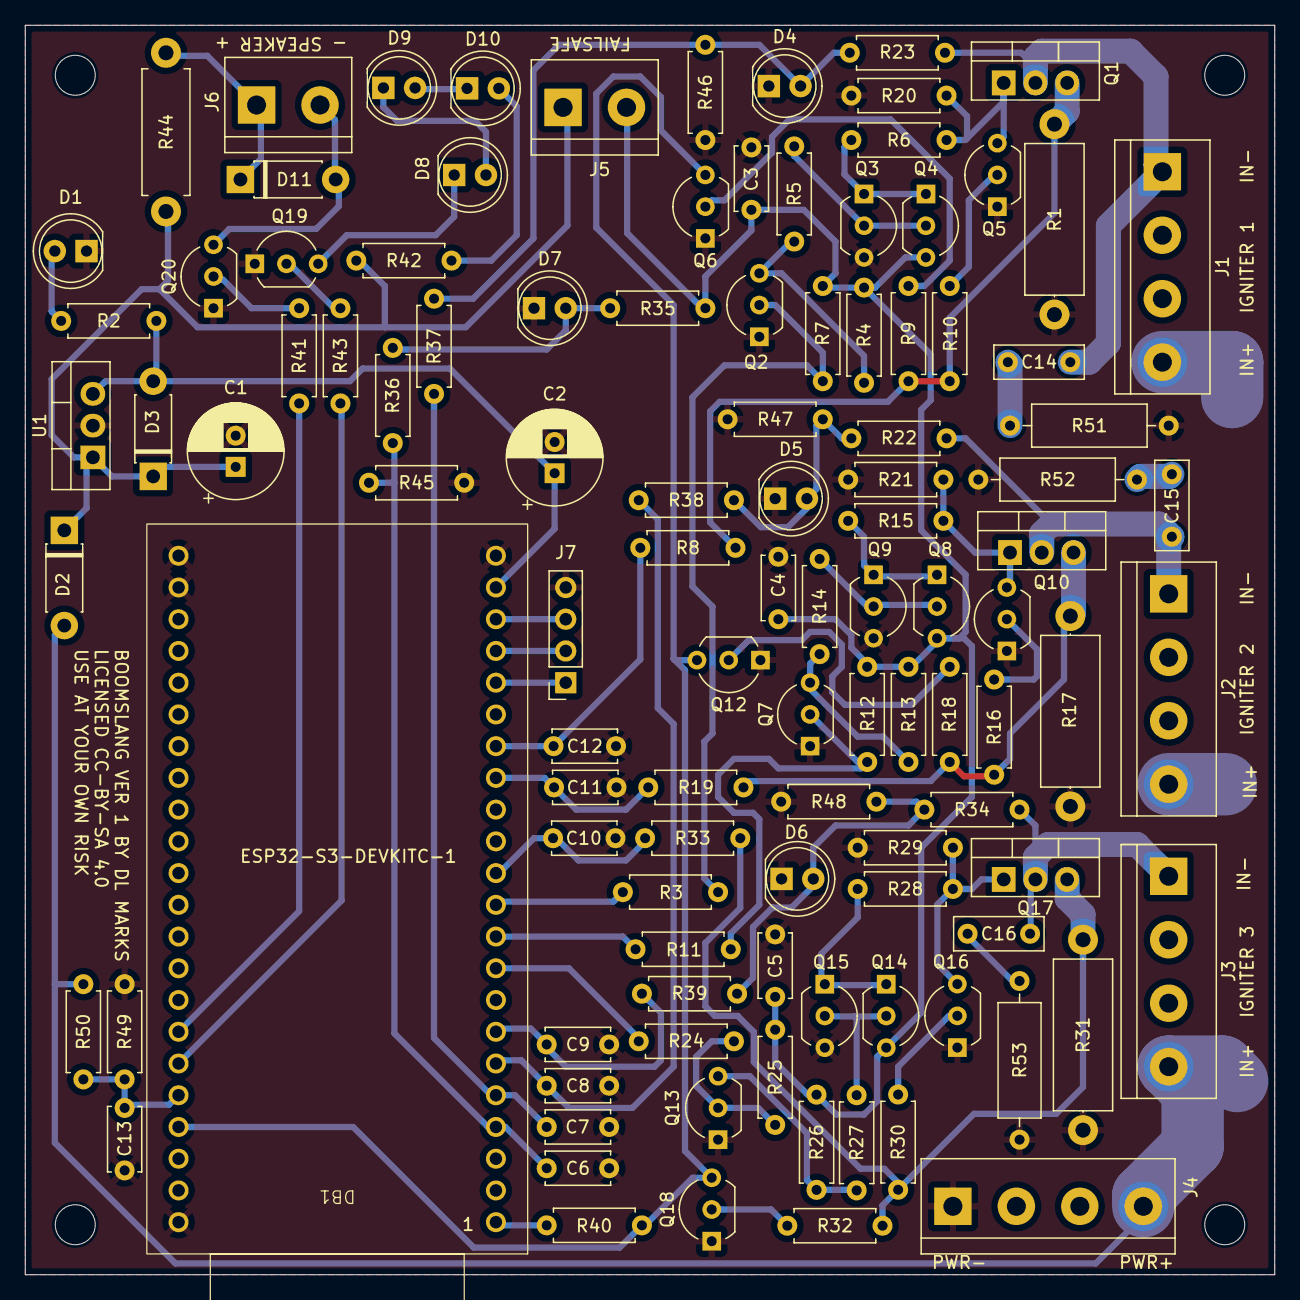
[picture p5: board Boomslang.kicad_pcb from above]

Board: 2 copper layers, 100.0 x 100.0 mm, 113 parts (0 on the bottom side), 66 nets.

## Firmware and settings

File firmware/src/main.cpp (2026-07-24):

#include <Arduino.h>
#include <WiFi.h>
#include <WebServer.h>
#include <ESPmDNS.h>
#include "esp_wifi.h"
#include "freertos/FreeRTOS.h"
#include "freertos/task.h"
#include "soc/gpio_reg.h"
#include "soc/soc.h"
#include "config.h"
#include "settings.h"
#include "arm_state.h"
#include "webpage.h"
#include "config_webpage.h"
#include "timing_webpage.h"
#include "stats_webpage.h"

WebServer server(80);

struct ChannelState {
  bool fireActive = false;
  uint32_t fireEndsAt = 0;
  float lastCurrentA = 0.0f;

  // Set by handleTrigger() when this channel is part of the current
  // sequence; cleared by loop()'s scheduling pass once its delay elapses
  // and it's either fired or skipped.
  bool scheduled = false;
  uint32_t fireAtMs = 0;

  // Whether this channel is included in the next TRIGGER. RAM only, not
  // persisted (must be an active, current choice) — set via /select, and
  // (per settings.checkContinuityOnArm) locked while armed so the set of
  // channels the live continuity monitor is watching can't shift underneath
  // it. Not cleared automatically after a sequence or a disarm; the
  // confirm() dialog before firing shows exactly what's selected either way.
  bool selected = false;

  // Peak and average current for this channel's most recent fire pulse.
  // Reset at the start of each pulse (startFirePulse()), sampled every
  // loop() iteration while fireActive, and then simply held — so they
  // remain readable after the pulse (and the whole sequence) ends, until
  // the channel fires again.
  float peakCurrentA = 0.0f;
  float avgCurrentA = 0.0f;
  float currentSumA = 0.0f;      // accumulator behind avgCurrentA
  uint32_t currentSampleCount = 0;

  // PWM cycling within this pulse (see startFirePulse()/loop()). Captured
  // from settings at fire-start, not read live, so a mid-pulse settings
  // change doesn't alter a cycle already in progress — same convention as
  // fireEndsAt capturing channelDurationMs at fire-start.
  bool pwmEnabled = false;
  uint32_t pwmPeriodMs = 0;
  uint32_t pwmOnMs = 0;
  uint32_t pwmNextToggleAtMs = 0;
  bool pwmPinOn = false;  // current logical pin state within the PWM cycle
};
ChannelState channels[NUM_CHANNELS];

// Live (non-latching) result of the arm-time continuity monitor: true if
// settings.checkContinuityOnArm is on, the device is armed, and at least
// one selected channel currently lacks continuity. Recomputed every loop()
// iteration (from channelContinuityCached, not a fresh read — see below),
// so it clears itself the instant the problem is fixed.
bool armContinuityError = false;

// Rolling battery/supply voltage reading. Refreshed round-robin with each
// channel's continuity (see loop()'s slowSampleStep) — at most one of these
// four analogRead()s happens per iteration, rather than all four every
// time. None of them need per-iteration freshness: the low-voltage lockout
// already debounces over 2s, and the arm-time continuity monitor is
// explicitly self-clearing/best-effort. This is the informational/display
// path only — the safety-relevant continuity re-checks at each channel's
// actual fire moment (scheduled-fire pass, PWM re-toggle) call
// hasContinuity() directly for a fresh read, not this cache.
float batteryVoltage = 0.0f;
bool channelContinuityCached[NUM_CHANNELS] = {false, false, false};
int slowSampleStep = 0;  // 0 = battery, 1..NUM_CHANNELS = that channel's continuity

// True if setup() actually ended up running as a WiFi station (relay mode
// requested and the connection succeeded) rather than hosting its own AP
// (the default, or relay mode's fallback on a failed connection) — set
// once in setup(), read in loop() to decide which RSSI API applies. Not
// the same thing as settings.wifiStationMode, which only reflects what
// was requested, not what's actually running.
bool wifiRunningAsStation = false;

// WiFi signal strength, checked roughly once a second (see loop() — a
// plain timer, independent of the ADC round-robin above, since this is a
// different subsystem with its own, much lower, overhead and doesn't need
// to share that budget). wifiRssiValid is deliberately false rather than
// showing a number that could be wrong: in AP mode, RSSI is only reported
// when exactly one station is connected — with zero or more than one
// connected, there's no single unambiguous "how's our link" answer, so
// the UI shows "NA" rather than guessing which one matters.
bool wifiRssiValid = false;
int wifiRssiDbm = 0;

// Browser watchdog (settings.browserWatchdogSec): updated to millis() by
// handleStatus() every time any page polls /status.json. loop() resets it
// continuously while DISARMED, so the clock only ever starts counting from
// the moment the arm switch actually closes ("since the arming cycle
// started"), and a poll from any page keeps resetting it while armed.
// browserWatchdogTripped guards against re-issuing the panic action every
// iteration once the threshold is crossed, and resets alongside the timer.
uint32_t lastStatusPollAtMs = 0;
bool browserWatchdogTripped = false;

// True from an accepted /trigger until every scheduled channel has either
// fired (and its pulse ended) or been skipped. Blocks a second /trigger
// regardless of settings.requireRearmAfterFire — you can never have two
// sequences in flight at once.
bool sequenceActive = false;

// Set by onFaultISR() the instant the shared FAULT line drops, and by a
// defensive poll in loop() as a backstop. Only cleared automatically while
// DISARMED, after re-checking the hardware line is actually clear — see
// loop()'s DISARMED-only fault-clearing pass.
volatile bool faultLatched = false;
bool faultLatchedPrev = false;       // loop()-only, for edge detection

// Written only by faultSampleTask, read by loop()/web handlers for display.
// Not lock-protected: this is best-effort diagnostic telemetry, not part of
// the safety path, so a rare torn read showing a stale/half-updated value is
// an acceptable tradeoff against the complexity of synchronizing it.
volatile bool faultSnapshotReady = false;
uint32_t faultSnapshotAtMs = 0;
float faultSnapshotA[NUM_CHANNELS] = {0, 0, 0};

TaskHandle_t faultSampleTaskHandle = nullptr;

// GPIO16/17/18 are all < 32, so a single write-1-to-set register write
// forces all three trigger outputs HIGH atomically.
constexpr uint32_t TRIGGER_PIN_MASK =
    (1u << PIN_TRIGGER[0]) | (1u << PIN_TRIGGER[1]) | (1u << PIN_TRIGGER[2]);

// Runs at interrupt level, IRAM-resident: no Serial, no heap/String, no
// calls into anything not IRAM-safe. In particular, analogRead() is NOT
// callable here — the ESP-IDF ADC driver takes a FreeRTOS mutex internally,
// and loop() is already calling it every iteration to refresh the current
// readings, so this ISR could easily fire while that lock is held elsewhere.
// Taking a lock from ISR context that way is undefined behavior.
//
// So: the two time-critical jobs (force every trigger off, latch the fault)
// happen right here, register-level. Sampling SENSE for diagnostics is
// handed off to a dedicated high-priority task via a notification — that
// task runs in normal FreeRTOS task context, where analogRead() is legal,
// and portYIELD_FROM_ISR ensures the scheduler switches to it the instant
// this ISR returns, ahead of loop() or anything else of lower priority.
void IRAM_ATTR onFaultISR() {
#if DEBUG_FAULT_TIMING
  // Marks ISR entry, essentially coincident with the FAULT edge itself —
  // scope this pin against FAULT to read off interrupt-latency directly.
  REG_WRITE(GPIO_OUT_W1TS_REG, 1u << PIN_DEBUG_TIMING);
#endif

#if !DEBUG_DISABLE_FAULT_SHUTOFF
  REG_WRITE(GPIO_OUT_W1TS_REG, TRIGGER_PIN_MASK);
#endif
  faultLatched = true;

  BaseType_t higherPriorityTaskWoken = pdFALSE;
  vTaskNotifyGiveFromISR(faultSampleTaskHandle, &higherPriorityTaskWoken);
  portYIELD_FROM_ISR(higherPriorityTaskWoken);
}

float readCurrentA(int ch) {
  int raw = analogRead(PIN_SENSE[ch]);
  float v = (raw / (float)ADC_MAX) * ADC_VREF;
  return v / settings.senseOhms[ch];
}

// Blocked on a task notification the rest of the time; woken by onFaultISR()
// to sample all three current-sense channels as close to the fault event as
// this platform can safely get. This is a diagnostic best-effort capture,
// not a safety mechanism — the trigger shutoff already happened in the ISR
// before this task even gets scheduled, and the true peak current may still
// have decayed somewhat by the time this runs, depending on how fast the
// hardware's own analog protection (Q5/Q10/Q16) and the igniter loop's
// inductance let it fall.
void faultSampleTask(void *) {
  for (;;) {
    ulTaskNotifyTake(pdTRUE, portMAX_DELAY);
    for (int i = 0; i < NUM_CHANNELS; i++) {
      faultSnapshotA[i] = readCurrentA(i);
    }
    faultSnapshotAtMs = millis();
    faultSnapshotReady = true;
#if DEBUG_FAULT_TIMING
    // Falling edge marks "all three SENSE channels sampled" — the gap
    // between this and the onFaultISR rising edge is the real number to
    // measure once there's hardware to scope it on.
    digitalWrite(PIN_DEBUG_TIMING, LOW);
#endif
  }
}

// Every other JSON field emitted below is a number or a bool computed by
// firmware; SSID/password are the one piece of free-form user text in
// /status.json and /config.json, so they're the one place a literal `"` or
// `\` in the input could otherwise break the JSON output.
void appendJsonString(String &out, const char *s) {
  out += '"';
  for (const char *p = s; *p; p++) {
    if (*p == '"' || *p == '\\') out += '\\';
    out += *p;
  }
  out += '"';
}

bool hasContinuity(int ch) {
  return analogRead(PIN_CONTINUITY[ch]) > CONTINUITY_OK_RAW;
}

float readBatteryVoltage() {
  int raw = analogRead(PIN_BATTERY);
  float v = (raw / (float)ADC_MAX) * ADC_VREF;
  return v * BATTERY_DIVIDER_RATIO + BATTERY_DIODE_DROP_V;
}
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
void loop() {
  server.handleClient();
  setSequenceActive(sequenceActive);

  // Round-robin: at most one of {battery, channel 1 continuity, channel 2
  // continuity, channel 3 continuity} gets a fresh analogRead() this
  // iteration, cycling through the rest. See channelContinuityCached's
  // comment for why none of these need per-iteration freshness. Done
  // before updateArmState() so it gets this iteration's value (freshly
  // sampled or still-cached) either way.
  if (slowSampleStep == 0) {
    batteryVoltage = readBatteryVoltage();
  } else {
    int ch = slowSampleStep - 1;
    channelContinuityCached[ch] = hasContinuity(ch);
  }
  slowSampleStep = (slowSampleStep + 1) % (NUM_CHANNELS + 1);

  updateArmState(batteryVoltage);

  uint32_t now = millis();

  // WiFi signal strength, once a second — a plain timer, independent of
  // the ADC round-robin above (different subsystem, doesn't share that
  // budget, and doesn't need per-iteration freshness either). See
  // wifiRssiValid's comment for why AP mode reports "invalid" rather than
  // a possibly-wrong number when there isn't exactly one connected
  // station.
  static uint32_t lastWifiRssiCheckMs = 0;
  if (now - lastWifiRssiCheckMs >= 1000) {
    lastWifiRssiCheckMs = now;
    if (wifiRunningAsStation) {
      wifiRssiValid = (WiFi.status() == WL_CONNECTED);
      if (wifiRssiValid) wifiRssiDbm = WiFi.RSSI();
    } else {
      wifi_sta_list_t staList;
      wifiRssiValid = (esp_wifi_ap_get_sta_list(&staList) == ESP_OK && staList.num == 1);
      if (wifiRssiValid) wifiRssiDbm = staList.sta[0].rssi;
    }
  }

  // Browser watchdog (settings.browserWatchdogSec, see PANIC and ABORT
  // buttons above): while DISARMED, keep resetting the clock — this means
  // it only ever starts counting from the moment the arm switch actually
  // closes. While armed, if no /status.json poll has landed within the
  // configured window, treat it exactly like the PANIC button: stop
  // anything firing and require a fresh disarm+rearm, unconditionally.
  // browserWatchdogTripped keeps this a one-shot action per arm cycle
  // rather than repeating every iteration while the poll gap persists.
  if (getArmState() == ArmState::DISARMED) {
    lastStatusPollAtMs = now;
    browserWatchdogTripped = false;
  } else if (!browserWatchdogTripped && settings.browserWatchdogSec > 0 &&
             (now - lastStatusPollAtMs) >= settings.browserWatchdogSec * 1000UL) {
    stopSequence();
    notifyPanicPressed();
    browserWatchdogTripped = true;
    Serial.printf("[panic] browser watchdog timeout (%lus) - no /status.json poll received\n",
                  (unsigned long)settings.browserWatchdogSec);
  }

#if DEBUG_LOOP_RATE
  static uint32_t loopIterCount = 0;
  static uint32_t lastLoopRateReportMs = 0;
  loopIterCount++;
  if (now - lastLoopRateReportMs >= 1000) {
    Serial.printf("[diag] loop() rate: %lu Hz (%.1f us/iteration avg)\n",
                  (unsigned long)loopIterCount, 1000000.0f / loopIterCount);
    loopIterCount = 0;
    lastLoopRateReportMs = now;
  }
#endif

  for (int i = 0; i < NUM_CHANNELS; i++) {
    // Rolling current reading for the UI; reads ~0 when idle since the
    // shunt is permanently tied to GND.
    channels[i].lastCurrentA = readCurrentA(i);

    // Peak/average accumulation for this pulse — sampled before checking
    // for pulse end below, so the very last active reading still counts.
    // Sampled every iteration regardless of PWM on/off phase, so avgCurrentA
    // naturally comes out duty-cycle-weighted (off-phase samples read ~0 and
    // pull the average down proportionally) with no special-case math needed.
    if (channels[i].fireActive) {
      if (channels[i].lastCurrentA > channels[i].peakCurrentA) {
        channels[i].peakCurrentA = channels[i].lastCurrentA;
      }
      channels[i].currentSumA += channels[i].lastCurrentA;
      channels[i].currentSampleCount++;
      channels[i].avgCurrentA = channels[i].currentSumA / channels[i].currentSampleCount;
    }

    // PWM toggling within an active pulse. Still within the overall
    // fireEndsAt window (checked separately below) and due for its next
    // edge.
    if (channels[i].fireActive && channels[i].pwmEnabled &&
        (int32_t)(now - channels[i].fireEndsAt) < 0 &&
        (int32_t)(now - channels[i].pwmNextToggleAtMs) >= 0) {
      if (channels[i].pwmPinOn) {
        // Turning off is always safe — no re-check needed, same as the
        // normal end-of-pulse release below.
        writeTriggerPinBlanked(i, HIGH);
        channels[i].pwmPinOn = false;
        channels[i].pwmNextToggleAtMs = now + (channels[i].pwmPeriodMs - channels[i].pwmOnMs);
      } else if (faultLatched || getArmState() != ArmState::READY || !hasContinuity(i)) {
        // Re-check right before turning back on — same reasoning as the
        // scheduled-fire pass's fire-time check: conditions can change
        // mid-sequence, and a PWM cycle can run for a while. Not the actual
        // safety mechanism (the arm switch opening cuts gate power outright
        // regardless of firmware) — belt-and-suspenders/logging, and stops
        // this channel's remaining PWM cycles rather than trying again.
        Serial.printf("[trigger] channel %d PWM cycle stopped early (fault=%d ready=%d continuity=%d)\n",
                      i + 1, faultLatched, getArmState() == ArmState::READY, hasContinuity(i));
        channels[i].fireActive = false;
      } else {
        writeTriggerPinBlanked(i, LOW);
        channels[i].pwmPinOn = true;
        channels[i].pwmNextToggleAtMs = now + channels[i].pwmOnMs;
      }
    }

    // Release any channel whose fire pulse has elapsed.
    if (channels[i].fireActive && (int32_t)(now - channels[i].fireEndsAt) >= 0) {
      // For a PWM channel already mid-off-phase, the pin is already high —
      // skip the redundant blanked write (and its blanking-window cost).
      if (!channels[i].pwmEnabled || channels[i].pwmPinOn) {
        writeTriggerPinBlanked(i, HIGH);
      }
      channels[i].fireActive = false;
      channels[i].pwmPinOn = false;
    }
  }

  // Scheduled-fire pass for the current trigger sequence (if any).
  for (int i = 0; i < NUM_CHANNELS; i++) {
    if (!channels[i].scheduled) continue;
    if ((int32_t)(now - channels[i].fireAtMs) < 0) continue;

    channels[i].scheduled = false;
    // Re-check right at fire time — conditions can change during a
    // multi-second delay. If the arm switch opens mid-sequence, the gate
    // drivers lose power regardless of what firmware does; this check is
    // belt-and-suspenders/logging, not the actual safety mechanism.
    if (faultLatched || getArmState() != ArmState::READY || !hasContinuity(i)) {
      Serial.printf("[trigger] channel %d skipped at fire time (fault=%d ready=%d continuity=%d)\n",
                    i + 1, faultLatched, getArmState() == ArmState::READY, hasContinuity(i));
      continue;
    }
    startFirePulse(i);
  }

  if (sequenceActive) {
    bool anyPending = false;
    for (int i = 0; i < NUM_CHANNELS; i++) {
      if (channels[i].scheduled || channels[i].fireActive) { anyPending = true; break; }
    }
    if (!anyPending) sequenceActive = false;
  }

  // Live arm-time continuity monitor (feature #1): recomputed every
  // iteration, not latched — clears itself the instant the problem is fixed
  // or the setting is turned off. Only meaningful while armed; the arm
  // state machine's own COUNTDOWN->READY progression is unaffected by this,
  // it only gates triggering. Uses channelContinuityCached (round-robin
  // sampled, up to NUM_CHANNELS iterations stale) rather than a fresh
  // hasContinuity() call — this monitor is explicitly best-effort/
  // self-clearing already, so that staleness is immaterial in practice.
  armContinuityError = false;
  if (settings.checkContinuityOnArm && getArmState() != ArmState::DISARMED) {
    for (int i = 0; i < NUM_CHANNELS; i++) {
      if (channels[i].selected && !channelContinuityCached[i]) {
        armContinuityError = true;
        break;
      }
    }
  }

  // Defensive backstop in case an edge was missed (e.g. FAULT was already
  // low before attachInterrupt() ran during setup()).
  if (!faultLatched && digitalRead(PIN_FAULT) == LOW) faultLatched = true;
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

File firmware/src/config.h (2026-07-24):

#pragma once
#include <Arduino.h>

// Pin map, derived from Boomslang-schematic.pdf (DB1 = ESP32-S3-DevKitC-1).
//
// TRIGGER1/2/3 are ACTIVE LOW. Hardware pulls each trigger node toward the
// FAILSAFE arm rail through a 100k resistor, so a floating/undriven GPIO
// (reset, brownout, crash before setup() runs) reads as "not firing" as
// long as the physical arm key at J5 is open. Firmware must claim these
// pins and drive them HIGH before anything else, and must only ever pulse
// them LOW briefly to fire.
constexpr int NUM_CHANNELS = 3;
constexpr int PIN_TRIGGER[NUM_CHANNELS]    = { 18, 17, 16 };
constexpr int PIN_SENSE[NUM_CHANNELS]      = { 10, 9, 8 };  // firing-current shunt readback (0.05R)
constexpr int PIN_CONTINUITY[NUM_CHANNELS] = { 5, 6, 7 };   // igniter continuity readback (LED-clamped)

constexpr int PIN_SENSE_FAILSAFE = 4;  // arm-loop (J5) presence sense, same LED-clamp scheme
constexpr int PIN_FAULT          = 1;  // shared hardware overcurrent fault, active LOW, open-collector
constexpr int PIN_AUDIBLE        = 41; // buzzer driver (J6)
constexpr int PIN_VISIBLE        = 42; // onboard white/blue strobe LEDs
constexpr int PIN_BATTERY        = 2;  // 12V supply, through a 1:11 resistor divider

// LEDC channel/resolution for the arming buzzer (PIN_AUDIBLE). Driven
// directly via ledcWrite()/ledcChangeFrequency() rather than tone()/
// noTone() — ledcWriteTone() (which tone() calls internally) always
// forces exactly 50% duty on every call, which is incompatible with
// volume control (settings.speakerVolume): frequency and duty need to be
// set independently. 10-bit resolution matches what tone() itself used.
constexpr uint8_t AUDIBLE_LEDC_CHANNEL          = 0;
constexpr uint8_t AUDIBLE_LEDC_RESOLUTION_BITS  = 10;

// ADC scaling: 12-bit, 3.3V reference, 11dB attenuation.
constexpr float ADC_VREF   = 3.3f;
constexpr int   ADC_MAX    = 4095;

// CONTINUITY and SENSE_FAILSAFE both work by pushing ~1mA through a red LED
// and reading the clamped voltage across it: that LED's forward voltage
// exceeds this threshold when the sensed loop (igniter or arm switch) is
// actually closed, and the node floats near 0V when open. Same circuit,
// same threshold, for both.
constexpr float LED_CLAMP_ARM_VOLTS = 1.25f;
constexpr int CONTINUITY_OK_RAW = (int)(LED_CLAMP_ARM_VOLTS / ADC_VREF * ADC_MAX);
constexpr int FAILSAFE_OK_RAW   = CONTINUITY_OK_RAW;

// Firing current sense: SENSE node voltage = I_fire * senseOhms[ch], direct
// (no divider) since the ADC input draws negligible current. The per-channel
// shunt value itself is a runtime-configurable setting (see settings.h), not
// a compile-time constant — it's field-replaceable hardware.

// Battery/supply voltage sense: PIN_BATTERY sees the 12V rail through a
// fixed 1:11 resistor divider (a PCB-fixed ratio, not field-replaceable
// like the current-sense shunts, so this is a compile-time constant).
constexpr float BATTERY_DIVIDER_RATIO = 11.0f;

// The battery rail passes through a series diode before reaching the
// divider, so the sensed voltage reads low by that diode's forward drop
// regardless of divider ratio. Added back after scaling in
// readBatteryVoltage() to recover the true battery voltage.
constexpr float BATTERY_DIODE_DROP_V = 0.7f;

// Debug timing instrumentation: toggles PIN_DEBUG_TIMING high as the first
// thing onFaultISR() does and low once faultSampleTask finishes reading all
// three SENSE channels. Put a scope or logic analyzer on this pin alongside
// FAULT to measure real end-to-end latency on actual hardware. Set to 0 for
// a field build — it's harmless left on (one extra register write in the
// ISR, negligible), but there's no reason to carry it once timing is known.
#define DEBUG_FAULT_TIMING 1
// GPIO13 rather than an ADC1 pin like GPIO2 — this signal is purely
// digital, so it's worth leaving ADC-capable header pins free for actual
// analog sensing. GPIO13 is only on ADC2 (which conflicts with WiFi and so
// isn't a pin you'd want for real analog use anyway), and is otherwise
// unconnected on the PCB.
constexpr int PIN_DEBUG_TIMING = 13;

// Logs loop() iterations/sec (and average iteration time) over Serial
// once a second — added to measure the real achievable ceiling for
// channelPwmHz, since loop() can't toggle a PWM-cycled pin faster than it
// can complete one full pass (three analogRead() calls every iteration
// for the live current display dominate that time — see readCurrentA()
// callers). Set to 0 for a field build.
#define DEBUG_LOOP_RATE 1
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

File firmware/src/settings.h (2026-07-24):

#pragma once
#include <Arduino.h>
#include "config.h"

// Runtime-configurable values, persisted to flash (NVS) so they survive
// power cycles. Each field's default here is what a fresh/blank board (or a
// firmware update that adds a new field) falls back to. Add new fields here
// as more settings are needed — loadSettings()/saveSettings() follow the
// same per-field pattern for each one.
struct Settings {
  // Per-channel current-sense shunt resistance, ohms. Schematic default is
  // 0.05R (R1/R17/R31) on all three channels, but this is field-replaceable
  // hardware, so it's runtime-configurable rather than a compile-time
  // constant. Used to convert a SENSE ADC reading to amps.
  float senseOhms[NUM_CHANNELS] = {0.05f, 0.05f, 0.05f};

  // Seconds between the arm switch (J5) being detected closed and firing
  // becoming permitted, so whoever closed it has time to clear the area.
  uint32_t armCountdownSec = 15;

  // Seconds allowed in READY before a fresh disarm+rearm is required, even
  // if the arm switch (J5) is still physically closed. 0 disables this
  // (READY can persist indefinitely, as before). This is a software-only
  // lockout on top of the hardware switch — it cannot re-power the gate
  // drivers on its own, and it cannot cut them either; it only blocks
  // TRIGGER, the same way panicLockedOut() does, until the switch is
  // observed open then closed again. Guards against "left armed and walked
  // away" rather than any electrical fault.
  uint32_t armTimeoutSec = 600;

  // Seconds allowed, while armed (COUNTDOWN or READY), without a
  // /status.json poll from a browser before an unconditional panic is
  // issued — same action as the PANIC button (stopSequence() +
  // notifyPanicPressed()): stops anything firing and requires a fresh
  // disarm+rearm, regardless of requireRearmAfterFire. Guards against the
  // operator's browser/phone losing contact (out of range, tab closed,
  // battery died) while the device is armed with no one actively watching
  // it. The clock starts fresh at the moment the arm switch closes and
  // resets on every poll, from any page — so it covers both "never polled
  // since arming" and "was polling, then stopped." 0 disables this
  // (matches prior behavior — no such check). Valid range 5-600s.
  uint32_t browserWatchdogSec = 60;

  // Whether the onboard strobe LEDs / buzzer indicate armed state at all.
  // Both default on to match common range-safety practice.
  bool visibleWhenArmed = true;
  bool audibleWhenArmed = true;

  // Buzzer volume, 0-10, mapped linearly to 0-50% PWM duty cycle (50% is as
  // loud as a square-wave drive gets — maximum RMS). Default 10 (50% duty)
  // matches the fixed duty tone()/ledcWriteTone() always used before this
  // was configurable, so upgrading a board doesn't change its loudness.
  uint32_t speakerVolume = 10;

  // If true, a TRIGGER press locks out any further TRIGGER press until the
  // arm switch is opened and closed again (a fresh disarm+rearm cycle,
  // countdown included). If false, another TRIGGER is accepted as soon as
  // the current sequence finishes, with no rearm needed.
  bool requireRearmAfterFire = true;

  // Per-channel offset (milliseconds, valid range 0-60000) from a TRIGGER
  // press to that channel's trigger output going low, for sequencing
  // multiple channels off one press.
  uint32_t channelDelayMs[NUM_CHANNELS] = {0, 0, 0};

  // Per-channel duration (milliseconds, valid range 0-30000) the trigger
  // output stays low once it fires.
  uint32_t channelDurationMs[NUM_CHANNELS] = {500, 500, 500};

  // Per-channel PWM cycling during that duration, for a lower average
  // heating rate than a full-on pulse (e.g. slow-heating igniter/nichrome
  // element rather than an instant e-match). 0 disables PWM entirely —
  // the channel is simply on for the whole duration, as before. Valid
  // range 1-300Hz — this is a real, measured ceiling, not just "doesn't
  // need to be precise": the toggle logic in loop() can't act faster than
  // loop() itself iterates (bench-measured at ~3kHz on this build after
  // WebServer::enableDelay(false); see main.cpp setup()), so requesting a
  // period comparable to one loop() iteration collapses duty accuracy
  // (1000Hz measured converging toward ~50% regardless of configured
  // duty). 300Hz keeps duty tracking usable down to ~10% duty. Default
  // 10Hz so a sensible frequency is already set if duty is later lowered
  // below 100% (see channelPwmDutyPercent).
  uint32_t channelPwmHz[NUM_CHANNELS] = {10, 10, 10};

  // Duty cycle (percent, 0-100) while channelPwmHz[ch] > 0. Default 100%
  // (and 100% at any other time) means continuously on for the whole
  // duration — no different from PWM being disabled — so a fresh board
  // fires exactly as before until duty is deliberately lowered.
  uint32_t channelPwmDutyPercent[NUM_CHANNELS] = {100, 100, 100};
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

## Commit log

2026-07-06 Added the PCB
    [Boomslang-B_Cu.gbr, Boomslang-B_Mask.gbr, Boomslang-B_Paste.gbr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]
2026-07-06 Add ESP32-S3 firmware for 3-channel ignition control
    Implements the fire/continuity/arm/fault logic matching the Boomslang
    schematic: active-low triggers (fail-safe by construction via the
    hardware pull-up to FAILSAFE), a level-1 ISR on the shared FAULT line
    that forces all trigger outputs high and latches until manually
    cleared, and a WiFi AP-hosted web UI for status and firing.
    [config.h, main.cpp]
2026-07-06 Sample SENSE channels near-instantly on fault via a notified task
    analogRead() takes a FreeRTOS mutex internally, which loop() already
    holds transiently every iteration, so calling it directly from
    onFaultISR would be unsafe (undefined behavior taking a lock from ISR
    context). Instead the ISR wakes a dedicated high-priority task via a
    task notification; that task samples all three SENSE channels in real
    task context immediately after being woken, giving a best-effort peek
    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
2026-07-06 Add persistent, flash-backed runtime settings
    Introduces a general Settings struct (settings.h/.cpp) persisted to
    NVS via Preferences, with compiled-in defaults that any missing key
    falls back to — covers a fresh board and firmware updates that add
    new fields alike. saveSettings() refuses to write while armed, since
    NVS commits briefly disable interrupts system-wide and shouldn't race
    the fault ISR.
    First field: per-channel current-sense shunt resistance (senseOhms),
    replacing the compile-time SENSE_OHMS constant, defaulting to 0.05R
    per channel to match the schematic (R1/R17/R31). No web UI to change
    it yet — that's future work — but the persistence plumbing is ready
    for it.
    Co-Auth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
    [config.h, main.cpp, settings.cpp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]
2026-07-06 Add web settings page for persistent runtime config
    New /config page (config_webpage.h) reads/writes the per-channel
    sense-shunt resistance via /config.json (GET) and /config (POST,
    same query-arg style as /fire), plus /config/reset to restore
    defaults. Shows a live armed/disarmed banner since saveSettings()
    declines to touch flash while armed; the value still applies
    in-memory immediately either way since it's only a diagnostic scaling
    factor, not part of any firing or fault decision. Linked from the
    main control page.
    [main.cpp]
2026-07-06 Add arm/failsafe state machine and trigger-sequence firing model
    New arm_state.h/.cpp implements DISARMED -> COUNTDOWN -> READY, sensing
    the J5 arm loop via SENSEFAILSAFE (LED-clamped divider, ~1.0V threshold)
    with 50ms debounce in both directions. Countdown length, and whether
    the strobe/buzzer indicate armed state at all, are now persisted
    settings; countdown gives whoever closed the arm switch time to clear
    the area. Countdown and ready states get audibly/visibly distinct
    patterns (440Hz slow pulse vs 1000Hz fast pulse) so they can be told
    apart without looking. Reverting to DISARMED is never delayed, only
    entering an armed state is.
    Firing model changes from one immediate per-channel FI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
    [config.h, main.cpp, settings.cpp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]
2026-07-06 Document trigger sequence flow in README
    Covers per-channel checkbox (session-only) + persisted delay, when
    TRIGGER is enabled, the fire-time recheck of armed/fault/continuity,
    and the requireRearmAfterFire lockout.
2026-07-06 Add continuity-based channel selection gating
    CONTINUITY and SENSE_FAILSAFE thresholds now derive from a single
    1.5V constant (LED_CLAMP_ARM_VOLTS), matching the actual LED forward
    voltage at ~1mA sense current, replacing earlier placeholder values.
    Channel selection is now tracked server-side (ChannelState.selected)
    rather than only existing in the query string of a /trigger POST, via
    a new /select endpoint - required so continuity can be monitored
    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
2026-07-06 Free GPIO2 for battery-voltage sensing, move debug pin to GPIO13
    GPIO2 (ADC1_CH1) now reads the 12V supply through a fixed 1:11
    resistor divider (BATTERY_DIVIDER_RATIO), exposed as battery_v in
    /status.json and shown on the main control page. The fault-timing
    debug marker moves to GPIO13, which is only on ADC2 (conflicts with
    WiFi anyway, so not a pin worth keeping free for real analog use).
    [config.h, main.cpp]
2026-07-06 Add configurable low-battery warning threshold
    New lowBatteryThresholdV setting (default 11.5V), persisted like the
    other settings. Exposed as low_battery in /status.json (live, not
    latching) and shown on the main control page when battery_v drops
    below it. Warning only - doesn't gate arming or triggering.
    [main.cpp, settings.cpp, settings.h]
2026-07-06 Add low-voltage lockout that blocks arming
    Reuses lowBatteryThresholdV rather than a second number. New
    lowVoltageLockoutEnabled setting (default on): when the arm switch
    closes while battery_v is under threshold, the device stays DISARMED
    instead of entering COUNTDOWN. Live and self-clearing - recomputed
    every updateArmState() call, so if voltage recovers while the switch
    is still closed it arms on the next iteration with no need to
    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
2026-07-06 Force disarm if voltage drops below threshold while already armed
    lowVoltageLockoutActive() is now checked every iteration in COUNTDOWN
    and READY, not just at the initial DISARMED->COUNTDOWN transition, so
    a voltage drop mid-countdown or while armed-and-ready reverts to
    DISARMED immediately - same as the arm switch opening. Since the
    switch is presumably still closed when this happens, the existing
    lowVBlocking/"Cannot arm" banner picks it up on the next iteration
    with no new UI work. Any in-flight trigger sequence is aborted by the
    scheduling pass's existing getArmState() != READY check, the same
    path already used when the switch opens mid-sequence.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
2026-07-06 Document battery voltage sensing, warning, and lockout in README
    Covers the GPIO2/1:11 divider sensing, the low-battery warning
    (lowBatteryThresholdV, default 11.5V), and the low-voltage lockout
    (lowVoltageLockoutEnabled) - both blocking the initial arm and
    forcing a disarm if voltage drops while already armed.
2026-07-06 Document continuity checks in README
    Covers the shared 1.5V LED-clamp threshold, the live arm-time
    continuity monitor (checkContinuityOnArm - self-clearing, also locks
    channel selection while armed), and the pre-trigger check
    (checkContinuityBeforeTrigger - hard disarm/rearm lockout, independent
    of requireRearmAfterFire), and how both relate to the existing
    per-channel fire-time recheck.
2026-07-06 Add continuous tone while triggered, plus ABORT/PANIC buttons
    Continuous tone: while a trigger sequence is running, the arm state
    machine's audible tone goes continuous (same frequency as the current
    state, no on/off pulsing) via the new setSequenceActive(), called
    from loop() each iteration. The strobe LED's blink pattern is
    unaffected.
    ABORT (/abort): immediately stops any in-progress sequence via the
    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
2026-07-06 Document ABORT and PANIC buttons in README
    Covers the shared stopSequence() immediate-stop helper, ABORT's
    no-lockout behavior, and PANIC's unconditional disarm/rearm lockout
    independent of requireRearmAfterFire.
2026-07-06 Document low-voltage lockout's lack of debounce in README
    Unlike SENSEFAILSAFE, the battery_v check has no debounce/hysteresis
    - a single raw ADC sample per loop() iteration. Notes the two real
    consequences: threshold-boundary flapping, and firing current itself
    sagging the same rail being sensed, which can self-abort a sequence
    via its own load transient rather than an actual low battery.
2026-07-06 Add debounce and hysteresis to the low-voltage lockout check
    computeLowVoltageLockout() in arm_state.cpp replaces the raw
    instantaneous battery_v comparison: the low-voltage condition must
    hold for LOW_VOLTAGE_DEBOUNCE_MS (2s, comfortably longer than a
    FIRE_PULSE_MS pulse) before the lockout engages, so firing current
    sagging the same rail it senses doesn't self-trigger a disarm. Once
    locked out, voltage must recover past threshold + LOW_VOLTAGE_
    HYSTERESIS_V (0.3V) before clearing, preventing flapping from noise
    right at the boundary. Same debounce shape already used for
    SENSEFAILSAFE, just tuned for a slower/noisier analog signal. Fixed
    constants, not settings, matching how the arm-switch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
2026-07-06 Add per-channel duration/offset in ms, and peak/average current registers
    Replaces the global FIRE_PULSE_MS constant with two per-channel
    settings: channelDelayMs (offset from TRIGGER press to that channel's
    output going low, 0-60000ms) and channelDurationMs (how long it then
    stays low, 0-30000ms), both persisted. Milliseconds rather than
    seconds for finer-grained control.
    Each channel also gets peakCurrentA/avgCurrentA, reset at the start
    of its pulse (startFirePulse()) and updated every loop() iteration
    while fireActive by sampling the existing rolling current reading
    before the pulse-end check (so the last active sample still counts).
    Both hold their value after the pulse ends so they ca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
    [config.h, main.cpp, settings.cpp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]
2026-07-06 Split web UI into Main / Timing / Stats / Settings pages
    Main (/) is trimmed to the operational screen: status banner, battery,
    per-channel checkbox + live continuity/firing state, and
    TRIGGER/ABORT/PANIC. Per-channel offset/duration inputs move to a new
    /timing page (same checkbox, same /select endpoint - selection is
    editable from both screens), and peak/average current from the last
    pulse moves to a new read-only /stats page. Settings (/config) is
    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
2026-07-06 Make WiFi SSID/password configurable, default to boomslang/liftoff!
    Moves AP_SSID/AP_PASSWORD from compile-time constants in config.h to
    persisted settings (wifiSsid[33]/wifiPassword[64], fixed-size buffers
    to avoid String heap fragmentation), editable on the settings page.
    Validated server-side: SSID 1-32 chars; password empty (open network)
    or 8-63 chars, matching WPA2-PSK's actual minimum - "liftoff" alone
    would have been rejected at 7 characters, hence the "!".
    WiFi.softAP() only runs once in setup(), so a saved change updates
    the setting immediately but only takes effect for the actual AP after
    a reboot; the settings page says so explicitly.
    Added appendJsonString() for safe JSON outp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
    [config.h, main.cpp, settings.cpp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]
2026-07-06 Document Timing/Stats pages in README, fix two stale references
    Adds a "Web UI pages" section covering all four pages (Main/Timing/
    Stats/Settings) and their shared nav. Also fixes two references left
    over from the UI split and the ms-based duration change: peak/average
    current now correctly points to /stats instead of "the control page",
    and the old FIRE_PULSE_MS mention updated to channelDurationMs.
2026-07-06 Break out GPIO2 battery sense and GPIO12-14 test points
    Adds the GPIO2 12V battery-voltage sense (1:11 divider, matches
    firmware's PIN_BATTERY/BATTERY_DIVIDER_RATIO) and breaks out
    GPIO12-14 as spare test points for timing tests and similar bring-up
    work. Regenerated gerbers and schematic/board renders to match.
    [Boomslang-B_Cu.gbr, Boomslang-B_Mask.gbr, Boomslang-B_Paste.gbr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]
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2026-07-06 Add GPIO14 factory-reset pin and WiFi relay (station) mode
    Factory reset: PIN_FACTORY_RESET (GPIO14), pulled up internally,
    checked once at boot with a chatter-safe multi-read before settings
    are loaded. Grounded at power-up resets every setting to its
    compiled-in default and persists immediately, overwriting NVS.
    GPIO14 has no strapping/special function on the ESP32-S3 (confirmed
    against Espressif's docs - unlike GPIO12 on the original ESP32).
    WiFi relay/station mode: new wifiStationMode setting (default off),
    reusing wifiSsid/wifiPassword as the target network's credentials.
    Attempts WiFi.begin() for up to 15s (WIFI_STA_CONNECT_TIMEOUT_MS) at
    boot, falling back to hosting its own AP on fa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
    [config.h, main.cpp, settings.cpp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]
2026-07-06 Update CHANGELOG for GPIO14 factory reset and WiFi relay mode
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2026-07-06 Add snubbers to MOSFET drains
    RC snubber on each channel's IRLZ44N drain to damp switching
    transients from the igniter/wiring inductance. Regenerated gerbers
    and schematic/board renders to match.
    [Boomslang-B_Cu.gbr, Boomslang-B_Mask.gbr, Boomslang-B_Paste.gbr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]
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2026-07-07 Changed snubber resistor footprint
    [Boomslang-B_Cu.gbr, Boomslang-B_Mask.gbr, Boomslang-B_Paste.gbr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]
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2026-07-14 Re-plot gerbers
    No design change — regenerated gerber/drill outputs from the
    already-committed board (snubber footprint change from 9ac0d92), plus
    removal of stray KiCad session lock files.
    [Boomslang-B_Cu.gbr, Boomslang-B_Mask.gbr, Boomslang-B_Paste.gbr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]
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2026-07-22 Correct battery diode drop and LED-clamp threshold
    Battery sense passes through a series diode ahead of the divider;
    readBatteryVoltage() now adds back its ~0.7V forward drop
    (BATTERY_DIODE_DROP_V) so battery_v reflects true battery voltage.
    Also lowers LED_CLAMP_ARM_VOLTS (continuity/arm-loop sense threshold)
    from 1.5V to 1.25V to better match the red LED's actual forward voltage.
    [config.h, main.cpp]
2026-07-22 Add live FAULT line indicator, fix choppy arming buzzer
    Main control page now shows the raw FAULT pin state (fault_pin_active)
    alongside the existing latched fault flag, so the live comparator state
    is visible independent of the sticky latch.
    Also fixes glitchy/choppy buzzer audio: updateArmState() was calling
    tone() on every unthrottled loop() iteration instead of only when the
    tone state actually changes, and tone() resets LEDC phase (and clicks
    audibly) on every call.
    [main.cpp]
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2026-07-22 Fix false FAULT trip on trigger via leading-edge blanking
    Pressing TRIGGER with no load connected was immediately producing a
    FAULT with 0A current — a switching transient at the trigger-pin edge,
    not a real overcurrent event (confirmed via the netlist: the RC snubber
    ties drain-to-GND directly, not through the sense shunt, so there's no
    real fault path with nothing connected).
    Adds writeTriggerPinBlanked(): a deterministic, interrupt-disabled
    critical section (FAULT_BLANKING_US, default 30us) around each
    deliberate trigger-pin write, filtering the transient without touching
    the actual per-channel hardware protection. Explicitly clears the GPIO's
    latched interrupt-status bit before re-ena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
    [config.h, main.cpp]
2026-07-22 Widen current-sense shunt resistance range to 0.01-100 ohm
    Was 0.001-10 ohm. Accommodates a wider range of field-replaced shunt
    values on the settings page and its server-side validation.
    [main.cpp]
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2026-07-22 Add buzzer volume control, tune fault blanking, fix battery lockout mismatch
    - Buzzer volume (speakerVolume, settings page, 0-10, default 10): maps to
    0-50% PWM duty. Moves the buzzer off tone()/noTone() (which always
    forces 50% duty) onto direct ledcChangeFrequency()/ledcWrite() calls,
    set independently and only re-issued on an actual change.
    - FAULT_BLANKING_US tuned down from 30us to 10us after bench testing
    confirmed the real transient clears well within that window.
    - arm_state.cpp's sampleBatteryVoltage() (used for the low-voltage arm
    lockout decision) now applies the same BATTERY_DIODE_DROP_V correction
    as main.cpp's readBatteryVoltage() (used for the displayed battery_v)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
    [config.h, main.cpp, settings.cpp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]
2026-07-22 Fix checkbox reboot desync, require rearm after fault, close multi-channel shutoff gap
    - Main/Timing pages could show stale checked checkboxes after a device
    reboot (channel selection isn't persisted, but the page only synced
    checkboxes from the server once, on first load). /status.json now
    includes uptime_ms; a drop means the device restarted, and both pages
    rebuild the channel list from server truth when they see one.
    - A FAULT didn't require a disarm+rearm before retriggering. Added a new
    sticky faultLockedOut()/notifyFaultOccurred() pair (arm_state.cpp, same
    shape as the PANIC lockout), set the instant any fault latches and
    cleared only at the same disarm->rearm point ever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
    [config.h, main.cpp]
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2026-07-23 Reduce overcurrent comparator base resistor from 1k to 100R
    Bench testing (scoped) found the local per-channel overcurrent
    comparator's pull-down transistor base resistor was slowing its own
    turn-on, letting fault current overshoot well past the ~13A trip
    threshold (38A) before the gate was actually pulled down. Reducing the
    base resistor from 1k to 100R speeds up that transistor's reaction,
    cutting the overshoot to ~15A. Verified in QUCS-S/ngspice simulation
    (Simulations/ThresholdTrip) as well as on the bench.
    Adds the QUCS-S simulation used to verify this.
    [Boomslang.kicad_pcb, Boomslang.kicad_sch, ThresholdTrip.sch]
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2026-07-23 Redesign nav as a 2x2 button grid, combine battery/fault line row
    Nav row on all four pages (Main/Timing/Stats/Settings) is now a 2x2 grid
    of button-styled blocks instead of an inline text row, with the font
    size doubled for easier one-handed tapping. Main page's Battery and
    FAULT line readouts moved onto a single flex row to make room.
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2026-07-24 Fix PWM duty accuracy by removing loop()'s ~1kHz WebServer floor
    Root cause of channelPwmHz producing a much higher actual duty cycle
    than configured (10% measured as ~50% at 1000Hz): loop() can't toggle a
    pin faster than it completes one full iteration. Traced the iteration
    time itself to WebServer::handleClient()'s flat delay(1) whenever no
    client is actively mid-request -- vTaskDelay()-backed, rounds up to at
    least one full 1ms FreeRTOS tick, capping loop() at ~1kHz regardless of
    per-iteration work. server.enableDelay(false) in setup() removes that
    floor, raising the measured rate from ~1kHz to ~3kHz.
    channelPwmHz's valid range lowered from 0-1000Hz to 0-300Hz to match
    what's actually ac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
    [config.h, main.cpp, settings.h]
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

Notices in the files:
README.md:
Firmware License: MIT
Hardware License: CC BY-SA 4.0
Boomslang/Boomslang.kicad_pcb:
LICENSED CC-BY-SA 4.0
